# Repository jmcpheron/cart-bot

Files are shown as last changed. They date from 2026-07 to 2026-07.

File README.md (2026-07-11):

# cart-bot — Garage Kiva-Bot

Two small autonomous ground robots that work as a coordinated pair to move loaded
garage shelving units, inspired by Amazon's Kiva robots. Each robot slides under a
skid attached to a 2×4 ft metal shelf, lifts it 1–2 inches with a lead screw, and
repositions it on mecanum wheels. The pair synchronizes over ESP-NOW.

**Current phase: the kitchen tester** — a minimal mecanum platform that validates
drive geometry, ESP32 firmware, and the ESP-NOW control link before the production
build. See [docs/project-brief.md](docs/project-brief.md) for the full vision.

## Repo map

| Path | Contents |
|---|---|
| `docs/project-brief.md` | Full project brief (with hardware corrections applied) |
| `docs/kitchen-tester/` | Build guide, wiring/pin map, test plan for the tester |
| `docs/production/roadmap.md` | Next steps after the kitchen tests pass |
| `docs/devlog.md` | Development log — the story so far, wrong turns included |
| `docs/kitchen-tester/tracker-quickref.md` | Tracker cheat sheet: live view, aiming, command ladder |
| `docs/production/tracker-setup.md` | Overhead-camera tracking: mounting, markers, bring-up |
| `firmware/` | PlatformIO project: `robot` + `transmitter` + `camera` targets, host-run unit tests |
| `cad/` | STEP design revisions, OpenSCAD sources, generated STL/reports/previews |
| `tools/cadlab/` | CAD revision tracker (uv/Python): inspect, diff, build, render |
| `tools/tracker/` | Overhead-camera ArUco tracker + closed-loop waypoint control (uv/Python) |
| `hardware/bom.md` | Bill of materials — on-hand tester parts and production shopping list |

## Firmware quickstart

```sh
cd firmware
pio test -e native          # kinematics unit tests, runs on your Mac, no hardware
pio run -e robot            # build robot firmware
pio run -e robot -t upload  # flash the robot ESP32 over USB
pio device monitor          # serial console (115200) — type `help`
pio run -e transmitter -t upload   # flash the second ESP32 (Test 3)
pio run -e camera -t upload        # flash the overhead ESP32-CAM (GPIO0 jumper first)
```

WiFi credentials for the LAN (camera + tracker) come from `secrets.env` at
the repo root — see `secrets.env.example`. Closed-loop tracking lives in
`tools/tracker/`; setup guide: [docs/production/tracker-setup.md](docs/production/tracker-setup.md)

After wiring, `spin` on the serial console cycles each wheel in turn to verify
the harness. Full wiring diagram + point-to-point checklist:
[docs/kitchen-tester/wiring.md](docs/kitchen-tester/wiring.md)

## Driving

Everything is hosted on the robot itself: join Wi-Fi **`cartbot-robot`**
(password in `firmware/src/robot/config.h`) and open **http://192.168.4.1**

- `/` — drive page: dual thumb-pads (left = forward/strafe, right = rotate,
  true multi-touch), speed scale, invert toggles, STOP. Pair a Bluetooth
  gamepad (e.g. a Joy-Con) with your **phone** and the page reads it via the
  browser Gamepad API — no firmware Bluetooth.
- `/tune` — per-motor raw-duty tuning + the RL pin-role finder.

### Dances (turtle programming + record/replay)

The drive page's **dance** panel programs LOGO-style step sequences
(forward 1s, rotate ⟳ 0.5s, pause, …) or records your live driving and
compresses it into editable steps. Programs play **on the robot** (they
survive the phone sleeping; the failsafe watchdog stays armed; any manual
input or STOP aborts instantly) and can be saved to 4 flash slots that
survive reboots. Playback is open-loop, so dances drift with wheel slip —
closed-loop tracking is on the production roadmap.

The second ESP32 (`transmitter` env) is no longer needed for driving; it
remains in the repo as the ESP-NOW testbed seeding the production two-robot
coordination. If both are powered, an active drive/tune page takes priority
and ESP-NOW resumes ~1s after the page goes idle.

## Status

- [x] Repo scaffold, docs, firmware skeleton, printable part sources
- [x] `mecanum::mix()` implemented — normalize-on-overflow, 10/10 tests green
- [x] Failsafe policy implemented — limp/stop ladder on command silence + battery
- [ ] Test 1 — bench motor sanity (FL verified on bench; FR/RL/RR pending)
- [ ] Test 2 — full drive on kitchen floor (serial `demo` command)
- [ ] Test 3 — ESP-NOW remote control (link verified 0-drop on bench; driving pending)
- [ ] Test 4 — sustained run + battery baseline

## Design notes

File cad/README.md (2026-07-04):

# Printed Parts

OpenSCAD sources in `openscad/`, design revisions as STEP in `step/`,
generated STLs in `stl/`, metric reports in `reports/`, previews in `img/`.

## Tracking design revisions

Chassis revisions are exported from Onshape as numbered STEP files
(`step/tt-mount-chassis-<n>.step`) with an optional `<name>.meta.toml` sidecar
holding design notes. The `tools/cadlab` CLI (ported from
[jmcpheron/pycon2026](https://github.com/jmcpheron/pycon2026)) turns each into
a diffable snapshot; CI (`.github/workflows/cad.yml`) regenerates everything
on push and auto-commits, so **the git diff of `reports/*.txt` is the design
change record**.

```sh
# from the repo root
uv run --project tools/cadlab pytest tools/cadlab/tests   # self-test
uv run --project tools/cadlab cadlab all                  # regen reports/stl/png
uv run --project tools/cadlab cadlab diff \
    cad/step/tt-mount-chassis-1.step cad/step/tt-mount-chassis-2.step
```

`diff` prints a markdown delta table (bbox, volume, surface area, PLA mass,
solids, triangles) between any two revisions — STEP files or report TOMLs.

Explainer pages for notable revisions live in `docs/design/`:
[chassis rev 1 → rev 2](../docs/design/chassis-rev1-to-rev2.md).

## Parts

| Part | Qty | Material | Settings | Notes |
|---|---|---|---|---|
| Jason's chassis | 1 | — | — | **The chassis actually in use** (vertical motor mounts, wheels outboard). Onshape design, tracked as `step/tt-mount-chassis-<n>.step` revisions |
| `cable-clip` | 4–6 | PLA | 0.2mm, 100% | Prints on its side, no supports |
| `tt-motor-bracket` | 0–4 | PLA | 0.2mm, 3 walls, 25% | **Unused** — superseded by Jason's chassis. Kept for the alternative flat-plate build |
| `chassis-plate` | 0–1 | PETG | 0.28mm, 4 walls, 30% | **Unused** — alternative flat-plate chassis, needs ~200mm bed |

## Regenerating STLs

Shared dimensions live in `openscad/params.scad`. After editing:

```sh
cd cad
for p in tt-motor-bracket cable-clip chassis-plate; do
  openscad -o stl/$p.stl openscad/$p.scad
done
```

Commit both the `.scad` change and the regenerated `.stl`.

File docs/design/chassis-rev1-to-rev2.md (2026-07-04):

# Chassis: rev 1 → rev 2

*2026-07-03 · after the first four-wheel spin test on rev 1*

Two problems surfaced when the mecanum wheels went onto the printed rev 1
chassis: the wheel hubs didn't fit through the cradle wall openings, and the
deck was wider than it needed to be. Rev 2 fixes both — **hub bores enlarged
Ø6 → Ø10 mm** (with an entry slot so the hub drops in) and the **deck narrowed
by 20 mm**.

## Side by side

| rev 1 — printed & tested | rev 2 — printing |
|:---:|:---:|
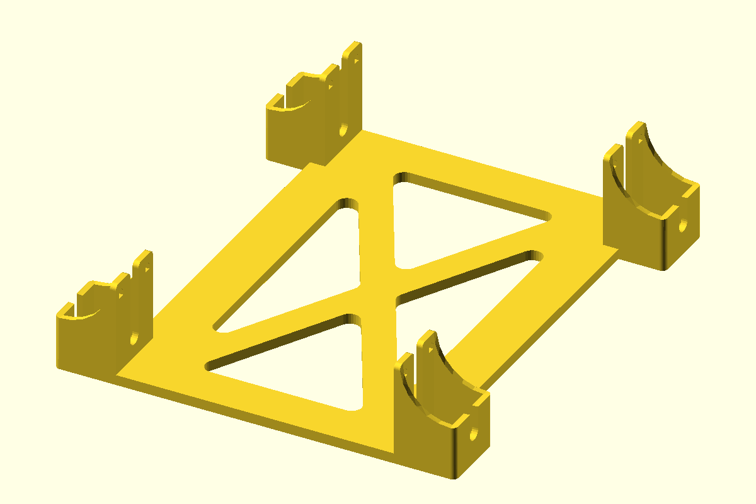
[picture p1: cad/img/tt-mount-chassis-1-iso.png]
rev 1 iso
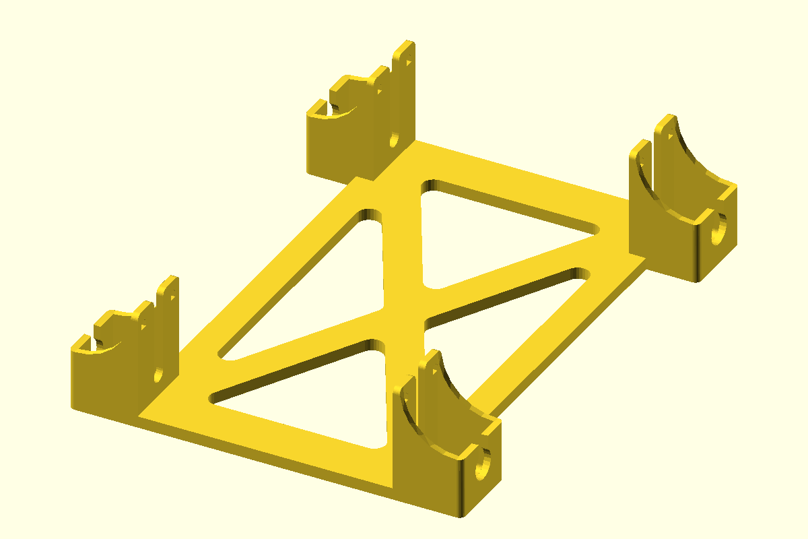
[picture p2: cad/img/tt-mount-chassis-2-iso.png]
rev 2 iso
|  |  |
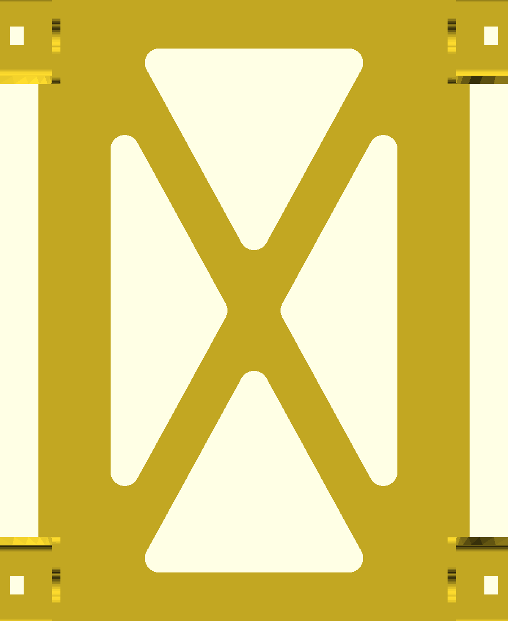
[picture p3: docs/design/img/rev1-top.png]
rev 1 top
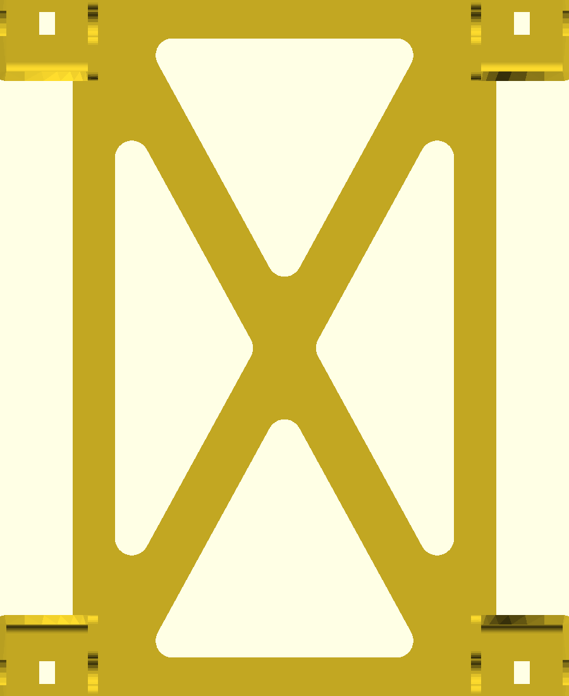
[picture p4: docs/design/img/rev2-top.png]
rev 2 top
|  |  |
| 156 × 180 × 40 mm | **136** × 180 × 40 mm |

## What changed, by the numbers

Generated with `cadlab diff` from the exact STEP geometry:

| Metric | rev 1 | rev 2 | Δ | Δ% |
|---|---|---|---|---|
| Bounding box X (mm) | 156.0 | 136.0 | −20.0 | **−12.8%** |
| Bounding box Y (mm) | 180.0 | 180.0 | 0 | — |
| Bounding box Z (mm) | 40.0 | 40.0 | 0 | — |
| Volume (mm³) | 77,289 | 62,548 | −14,741 | **−19.1%** |
| Surface area (mm²) | 56,000 | 48,421 | −7,580 | −13.5% |
| PLA @ 100% infill (g) | 95.8 | 77.6 | −18.2 | −19.0% |
| Solids | 5 | 5 | 0 | — |

Almost all of the removed volume is the deck narrowing; the bore enlargement
is geometrically small but is the change that makes the wheels mountable.

## The hub bore, in cross-section

Both revisions sliced by the **same plane** (x = −66 mm, through the
front-left motor cradle, perpendicular to the wheel axle). Gray fill is
rev 1; orange outline is rev 2:

cradle cross-section overlay

Rev 1's cradle wall had only a Ø6 shaft pass-through — the small gap visible
in the gray wall. Rev 2 opens it to a **Ø10 bore with a slot out to the motor
pocket**, so the wheel's hub collar passes through the wall instead of
colliding with it, and there's clearance around the hub while it spins.

Measured straight from the STEP's cylindrical faces (four bores each):

| | rev 1 | rev 2 |
|---|---|---|
| Hub bore radius | 3.0 mm | **5.0 mm** |
| Bore axis | along X (wheel axle), center 10.3 mm above the deck | unchanged |
| Cradle saddle (motor seat) | r 19.3 mm | unchanged |

The full-height slice (both left cradles, same plane) for context:

full cross-section overlay

## Reproducing this page's data

```sh
uv run --project tools/cadlab cadlab diff \
    cad/step/tt-mount-chassis-1.step cad/step/tt-mount-chassis-2.step
```

The cross-sections are exact BREP cuts (build123d slab-intersection at
x = −66, exported with `ExportSVG`), not mesh slices — the STL tessellation
isn't watertight enough for OpenSCAD's CGAL projection. Bore radii come from
enumerating the STEP's cylindrical faces (`GeomType.CYLINDER`).

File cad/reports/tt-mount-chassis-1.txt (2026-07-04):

File:           tt-mount-chassis-1.step
Schema:         AP242_MANAGED_MODEL_BASED_3D_ENGINEERING_MIM_LF { 1 0 10303 442 3 1 4 }
Originating:    ONSHAPE BY PTC INC, 1.217
Timestamp:      2026-07-04T05:18:35Z
Solids:         5   Top-level children: 5
Bounding box:   X[-78.257, 77.743]  Y[-89.952, 90.048]  Z[-1.705, 38.295]
Size:           156.0 × 180.0 × 40.0 mm
Volume:         77,289.1 mm³   (≈95.8 g PLA @ 100% infill)
Surface area:   56,000.0 mm²
Center of mass: (-0.257, 0.048, 3.658)
Tessellation:   2,588 triangles  (linear=0.1 mm  angular=0.5 rad)

Design metadata:
  design.revision: 1
  design.status: printed and tested
  design.date: 2026-07-03
  design.notes: Initial chassis: vertical TT motor mounts, wheels outboard on the D-shafts. Validated in the first four-wheel spin test.

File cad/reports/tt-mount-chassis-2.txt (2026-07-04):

File:           tt-mount-chassis-2.step
Schema:         AP242_MANAGED_MODEL_BASED_3D_ENGINEERING_MIM_LF { 1 0 10303 442 3 1 4 }
Originating:    ONSHAPE BY PTC INC, 1.217
Timestamp:      2026-07-04T05:22:29Z
Solids:         5   Top-level children: 5
Bounding box:   X[-68.257, 67.743]  Y[-89.952, 90.048]  Z[-1.705, 38.295]
Size:           136.0 × 180.0 × 40.0 mm
Volume:         62,547.7 mm³   (≈77.6 g PLA @ 100% infill)
Surface area:   48,420.5 mm²
Center of mass: (-0.257, 0.048, 4.403)
Tessellation:   2,700 triangles  (linear=0.1 mm  angular=0.5 rad)

Design metadata:
  design.revision: 2
  design.status: printing
  design.date: 2026-07-03
  design.changes_from: tt-mount-chassis-1
  design.notes: Bigger hub bore so the mecanum wheel hub fits through with clearance; deck narrowed.

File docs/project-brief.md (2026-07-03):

# Garage Kiva-Bot — Project Brief

## Project Summary

The goal is to build two small autonomous ground robots that work as a coordinated
pair to move loaded garage shelving units around the garage floor — inspired by the
Amazon Kiva/Robotics system. Each robot slides under a custom bottom skid attached
to a standard 2×4 ft metal garage shelf, lifts it 1–2 inches off the ground using a
lead screw mechanism, then repositions it using mecanum wheel drive. The two robots
communicate wirelessly (ESP-NOW) to synchronize their lift so the shelf stays level
during movement. When not in use, the robots return to an autonomous charging dock.

The full production system uses 12V geared motors with Hall encoders (JGB37-520),
BTS7960 high-current motor drivers, 4S 18650 battery packs, NEMA 17 steppers for
the lift, and MPU-6050 tilt sensing for safety. But before any of that gets built,
we validate the core ideas on a cheap kitchen-floor test platform first.

---

## Kitchen Tester — What It Is

The kitchen tester is a minimal, low-cost prototype that proves out the mecanum
drive geometry and ESP32 control code before committing to the full build. It is
not expected to lift anything. It is not expected to run for hours. It just needs
to drive in all eight directions, strafe cleanly, rotate in place, and respond to
commands from a second ESP32 over ESP-NOW.

### Hardware on Hand

| Item | Qty | Notes |
|---|---|---|
| DORHEA TT Motor + 69mm Wheel Kit | 4 sets | 3–6V, 1:48, ~200 RPM at 6V (kit wheels unused — mecanums replace them) |
| Eujgoov 48mm Mecanum Wheels | 2 pairs (4 wheels) | TT-shaft compatible, rubber rollers |
| BOJACK L298N Dual H-Bridge Driver | 4× (use 2) | Controls 2 motors each, 3.3V logic OK |
| URGENEX 7.4V 2S LiPo, 1000mAh, 35C | 2× (use 1) | JST connector, ~51g |
| ESP32 WROOM-32 (38-pin) | 2× from stash | Robot + transmitter; dual-core, ESP-NOW, PWM |

Two L298N boards cover all four motors (two motors per board). The LiPo feeds the
L298N motor supply directly at 7.4V; the L298N's onboard 5V regulator feeds the
ESP32's VIN pin. No separate power converter needed.

> **Power notes (corrections to the original draft):**
> - The L298N drops ~1.4–2.5V through its output transistors, so the 3–6V TT
>   motors see roughly 5–6V from the 7.4V pack. **This is a feature** — don't
>   "fix" it with a buck converter or the motors will be overdriven.
> - Keep the L298N's onboard 5V-regulator jumper **ON** (7.4V input gives the
>   78M05 enough headroom). Add a 470–1000µF electrolytic across the motor
>   supply near the drivers; motor stall transients otherwise cause ESP32
>   brownout resets. All grounds must be common.
> - A 100k/33k divider from pack + to GPIO 34 lets firmware watch pack voltage
>   and enforce the 6.8V (3.4V/cell) cutoff automatically.

### Chassis

A piece of 1/4-inch plywood or a printed plate, roughly 180–200mm square, with the
four TT motors mounted at the corners. Wheels must form the standard mecanum
X-pattern — viewed **from above**, the roller axes form an X:

```
FL ⟍   ⟋ FR
RL ⟋   ⟍ RR
```

Rollers on FL and RR lean one direction; FR and RL lean the other. This is what
enables sideways movement. **Getting this orientation wrong is the most common
first mistake — check it against `docs/kitchen-tester/build-guide.md` before
wiring anything.**

TT motors screw into printed brackets (`cad/`). The 48mm mecanum wheels press
directly onto the TT motor's D-shaft. No axle hardware needed for the tester.

---

## Wiring

See [`docs/kitchen-tester/wiring.md`](kitchen-tester/wiring.md) for the full pin
map and power tree. Key change from the original draft: the pin map avoids **all**
ESP32 strap pins (0, 2, 5, 12, 15) — the draft assigned GPIO 12, which selects
1.8V flash voltage if it reads high at boot and can prevent the board from booting.

---

## Firmware Structure

### Mecanum Kinematics

The core math takes three velocity inputs — forward (vx), strafe (vy), and turn
rate (ω) — and mixes them into four wheel speeds:

```
FL = vx + vy + ω
FR = vx − vy − ω
RL = vx − vy + ω
RR = vx + vy − ω
```

Sign convention: **vx+ = forward, vy+ = strafe right, ω+ = clockwise** (from
above). Each result is scaled and clamped to [−255, 255] and mapped to PWM duty +
direction pins. Open-loop at this stage — no encoders — the goal is validating
that the geometry produces the right movement. The math lives in
`firmware/lib/kinematics/` as a dependency-free library with host-run unit tests,
and is reused unchanged by the production robots.

### ESP32 Task Layout

Two FreeRTOS tasks on the dual-core ESP32:

- **Core 0 — Motor task:** reads the current velocity setpoint from a shared
  store, evaluates the failsafe policy, computes wheel speeds, updates PWM
  outputs every 20ms.
- **Core 1 — Comms task:** serial console + ESP-NOW receive. Updates the shared
  setpoint when a command arrives. Watchdog: no command for 500ms → failsafe.

### Command Protocol (ESP-NOW)

Packed struct, exactly 6 bytes (`firmware/lib/protocol/`):

```c
typedef struct __attribute__((packed)) {
    int8_t   vx;     // forward/back, -100..100
    int8_t   vy;     // strafe right/left, -100..100
    int8_t   omega;  // rotation CW/CCW, -100..100
    uint8_t  cmd;    // 0=drive, 1=stop, 2=ping
    uint16_t seq;    // sequence number for drop detection
} robot_cmd_t;
```

The transmitter sends this at ~10Hz; ESP-NOW frames carry their own CRC, so the
sequence number is only for measuring drops. The transmitter ESP32 hosts a Wi-Fi
AP with a phone-browser joystick page.

---

## Test Sequence

Full checklists with results logs: [`docs/kitchen-tester/test-plan.md`](kitchen-tester/test-plan.md).

1. **Power-up and motor sanity** — bench-test each motor/driver channel from the
   serial console before assembly.
2. **Full drive on kitchen floor** — forward/back, strafe, rotate, diagonal via
   the scripted `demo` sequence over USB serial.
3. **ESP-NOW control from second ESP32** — phone joystick → transmitter →
   robot; validate latency, watchdog, packet loss.
4. **Sustained run and battery life** — 15 min continuous, temperature and
   voltage logging; sets expectations for production 4S pack sizing.

---

## What This Proves (and What It Doesn't)

| Validated by kitchen tester | Deferred to production build |
|---|---|
| Mecanum drive geometry works | Torque under load (500+ lb shelf) |
| ESP32 mecanum firmware | Encoder closed-loop velocity control |
| ESP-NOW latency and reliability | Two-robot lift synchronization |
| Battery voltage/run-time baseline | Lead screw lift mechanism |
| L298N + ESP32 3.3V logic compatibility | BTS7960 high-current driver behavior |
| Basic obstacle response (manual) | Automated docking and charging |

---

## Printed Parts

Sources and print settings in [`cad/`](../cad/README.md):

- **TT motor brackets** — 4× corner cradles, PLA, non-structural.
- **Chassis plate** — optional printed alternative to plywood, PETG, 4mm.
- **Cable clips** — keep the LiPo lead and L298N jumpers out of the rollers.

---

## Next Steps After Kitchen Tests Pass

See [`docs/production/roadmap.md`](production/roadmap.md).

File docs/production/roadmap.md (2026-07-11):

# Production Roadmap — after the kitchen tests pass

## Next milestone: closed-loop tracking (kitchen scale)

Open-loop dances drift because the TT motors are inconsistent and the
mecanums skid — by design, position feedback is the fix, not better motors.
Plan, in increasing order of capability:

1. **Gyro heading-hold (cheap interim): BUILT — awaiting hardware bring-up.**
   MPU-6050 (GY-521) on I²C, SDA=GPIO13 SCL=GPIO33 (`src/robot/imu.{h,cpp}`,
   raw registers, no library). Yaw-hold PI (`lib/heading`) trims ω whenever
   the robot translates with w=0 — kills rotational drift, does nothing for
   position. Dances also gained gyro-terminated turns: `t,<deg>,<w>` steps
   (`lib/dancescript`) end at the measured angle, not a timer. Debug:
   `/imu` endpoint, serial `imu` command, "gyro square" preset on the drive
   page. NOTE before wiring: GPIO 33 was the ORIGINAL RL_IN1 — confirm no
   stray harness wire is still on it (same caveat as 32).
2. **Overhead camera + ArUco (the real thing): BUILT — see
   [tracker-setup.md](tracker-setup.md).** One downward-looking AI-Thinker
   ESP32-CAM (`pio run -e camera`) streams frames; `tools/tracker/` (uv
   project like cadlab) detects a printed ArUco marker on the robot's roof,
   maps it through a floor-marker homography, and sends `/cmd` corrections
   at 10 Hz. Waypoint following = `tracker goto` / `tracker route`.
   ESP32-CAMs never do vision themselves — they're too weak; they only
   stream.
3. **Multi-camera coverage:** only when one camera's view isn't enough
   (garage scale). Homographies + hand-off; genuinely advanced, defer.

1. **Order drivetrain hardware** — JGB37-520 12V gearmotors with Hall encoders,
   BTS7960 drivers, 4S 18650 pack + BMS.
2. **Design production chassis** in Onshape — 2020 aluminum extrusion or bent
   sheet metal; link the Onshape doc here and commit exported STEP/STL to `cad/`.
3. **Closed-loop velocity control** — encoder ISRs + PID per wheel; reuse
   `lib/kinematics` unchanged, the mix output becomes a velocity setpoint instead
   of a PWM duty.
4. **Safety** — MPU-6050 tilt sensing, tilt-abort on lift; extend the failsafe
   policy from the tester (`src/robot/failsafe.cpp` is the seed).
5. **Lift sub-assembly** — NEMA 17 + lead screw; 1,000-cycle stress test rig.
6. **Shelf skid frame** — square steel tube, H-shape, for the 2×4 ft shelves.
7. **Two-robot coordination** — extend `lib/protocol` from one-way drive
   commands to a leader/follower lift-sync handshake (the seq/ack groundwork is
   validated by kitchen Test 3).
8. **Docking + charging** — autonomous return to dock; contact pads.

## Open questions to resolve before ordering

- Shelf + contents worst-case weight → wheel count/size and motor torque margin.
- Garage floor surface (sealed concrete?) → mecanum roller compound choice.
- Lift point geometry on the 2×4 shelves → skid design drives robot footprint.

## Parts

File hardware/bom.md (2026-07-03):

# Bill of Materials

## Kitchen tester (on hand)

| Item | Qty used / on hand | Notes |
|---|---|---|
| DORHEA TT motor, 1:48, 3–6V | 4 / 4 | Kit's 69mm plastic wheels unused |
| Eujgoov 48mm mecanum wheels | 4 / 4 | 2 left + 2 right; split pairs across diagonals |
| BOJACK L298N dual H-bridge | 2 / 4 | Spares cover a blown board |
| URGENEX 2S LiPo 7.4V 1000mAh 35C | 1 / 2 | JST; second pack for swap during long tests |
| ESP32 WROOM-32 38-pin dev board | 2 / stash | Robot + transmitter |

## Kitchen tester (to buy / find in stash)

| Item | Qty | Notes |
|---|---|---|
| 470–1000µF ≥16V electrolytic cap | 1–2 | Bulk cap across motor rail (brownout fix) |
| 100kΩ + 33kΩ resistors, 1% | 1 ea | Battery sense divider → GPIO 34 |
| M3 screws (×30 for motors, ×8 for brackets) + nuts | ~20 | TT motor mounts |
| Dupont jumpers, 20cm | ~20 | Logic wiring |
| 18–20 AWG silicone wire | 1m | Battery → drivers |
| JST connector pigtail | 1 | Match the URGENEX pack |
| Velcro strap | 1 | Battery retention |
| Chassis: 1/4" plywood offcut ~200mm sq | 1 | Or print `chassis-plate` in PETG |

## Production build (deferred — do not order until kitchen tests pass)

| Item | Qty (per robot × 2) | Notes |
|---|---|---|
| JGB37-520 12V gearmotor w/ Hall encoder | 4 | Torque spec TBD by shelf weight measurement |
| BTS7960 43A driver | 4 | One per motor for closed-loop |
| Mecanum wheels, 97mm+ steel hub | 4 | Roller compound TBD by floor surface |
| NEMA 17 stepper + lead screw (Tr8x8) | 1 | Lift mechanism |
| Stepper driver (TMC2209 or DM542) | 1 | |
| MPU-6050 IMU | 1 | Tilt-abort |
| 4S 18650 pack + BMS | 1 | Capacity TBD from Test 4 baseline |
| ESP32 WROOM-32 | 1 | Same firmware family as tester |
| Steel square tube for shelf skid | — | H-frame per shelf |

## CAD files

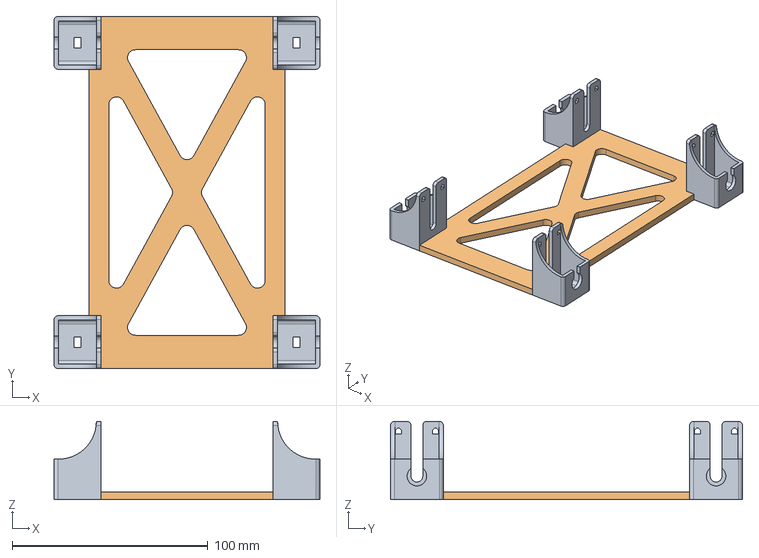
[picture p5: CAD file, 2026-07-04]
cad/step/tt-mount-chassis-2.step
136.0 x 180.0 x 40.0 mm
tt-mount x 4

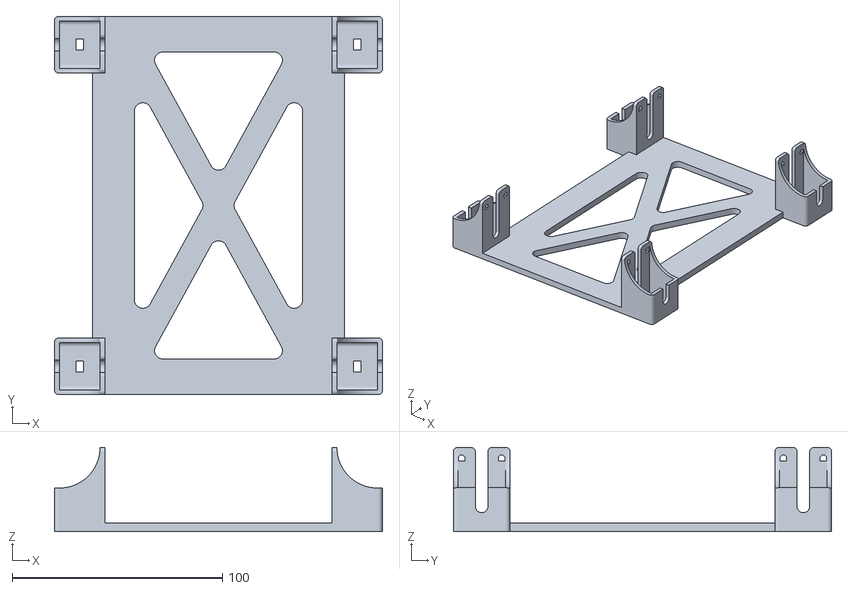
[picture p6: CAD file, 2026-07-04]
cad/stl/onshape-chassis-and-tt-mounts.stl
156.0 x 180.0 x 40.0

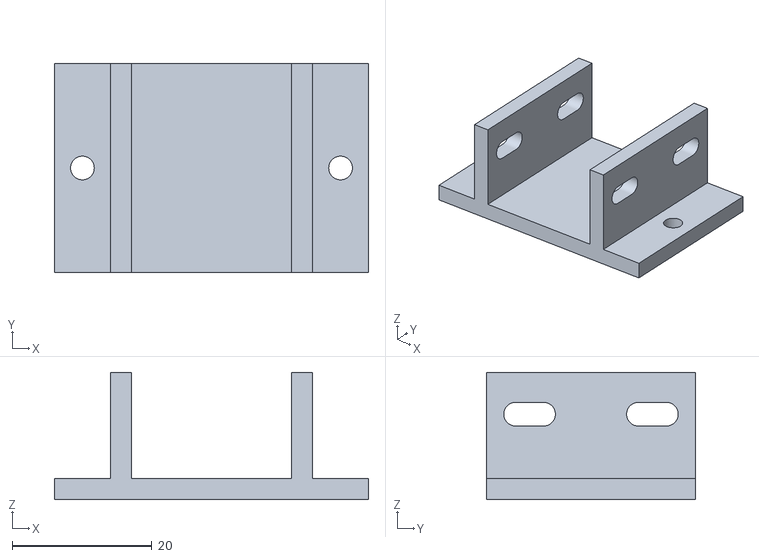
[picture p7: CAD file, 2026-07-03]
cad/stl/tt-motor-bracket.stl
45.0 x 30.0 x 18.2

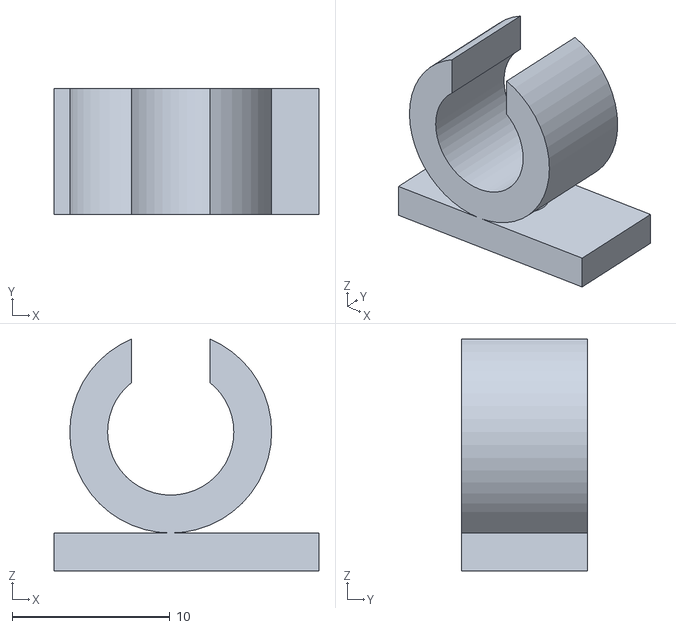
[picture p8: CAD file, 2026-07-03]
cad/stl/cable-clip.stl
16.8 x 8.00 x 14.7

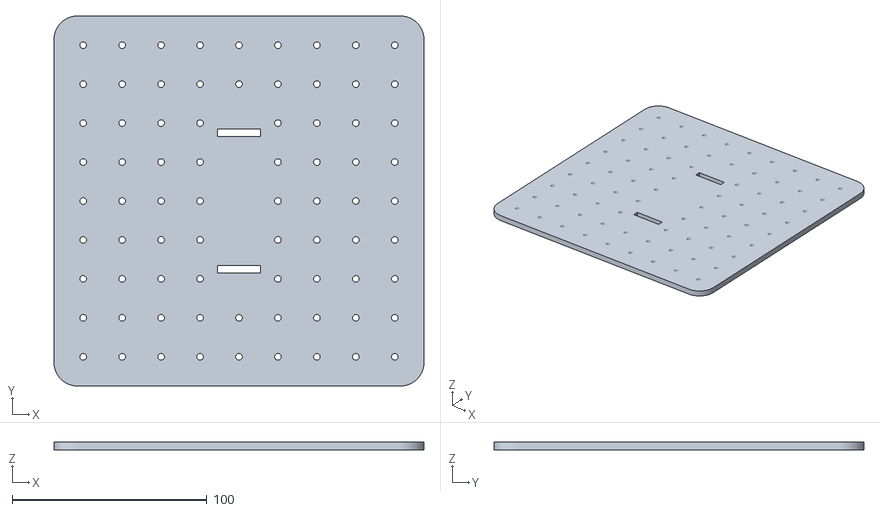
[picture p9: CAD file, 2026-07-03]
cad/stl/chassis-plate.stl
190.0 x 190.0 x 4.00

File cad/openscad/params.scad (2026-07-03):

// Shared dimensions for the kitchen tester printed parts.
// ⚠ TT motor clones vary by ±0.5mm — measure YOUR DORHEA motors and print ONE
// bracket to check fit before running off all four.

// ---- TT motor (yellow gearbox type) ----
tt_body_len    = 65.0;   // gearbox + can, excluding shaft
tt_body_w      = 22.5;   // across the flats
tt_body_h      = 18.5;
tt_hole_d      = 3.2;    // M3 clearance
tt_hole_space  = 17.6;   // between the two gearbox through-holes — MEASURE THIS
tt_hole_z      = tt_body_h / 2;  // holes run through mid-height of the box

// ---- printing ----
fit_clr   = 0.25;  // per-side clearance for press/slide fits
wall      = 3.0;
m3_clr    = 3.4;   // M3 clearance hole
$fn       = 48;

// ---- chassis ----
plate_size  = 190;   // square, mm
plate_thick = 4;
grid_pitch  = 20;    // M3 mounting-hole grid

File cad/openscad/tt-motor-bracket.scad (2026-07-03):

// TT motor bracket — U-channel cradle, 4 needed (all identical).
//
// The motor drops into the channel; two M3×30 screws pass through both walls
// and the motor's gearbox through-holes. Wall holes are SLOTS (±2mm along the
// motor axis) to absorb clone-to-clone hole-position variance. The base bolts
// to the chassis plate with two M3 screws on the 20mm grid.
//
// Print: PLA, 0.2mm layers, 3 perimeters, 25% infill, no supports
// (slots print as bridges — they're short, any printer handles it).

include <params.scad>

channel_w  = tt_body_w + 2 * fit_clr;       // motor slides in
bracket_len = 30;                            // along the motor axis
wall_h     = tt_hole_z + 6;                  // wall covers holes + margin
base_thick = 3;
base_ear   = 8;                              // ear width outside each wall
slot_len   = 4;                              // hole slop along motor axis

module wall_slot() {
    // M3 through-slot at motor-hole height, elongated along motor axis (Y)
    hull()
        for (y = [-slot_len/2, slot_len/2])
            translate([0, y, base_thick + tt_hole_z])
                rotate([0, 90, 0])
                    cylinder(d = m3_clr, h = 100, center = true);
}

module tt_motor_bracket() {
    difference() {
        union() {
            // base with mounting ears
            translate([-(channel_w/2 + wall + base_ear), -bracket_len/2, 0])
                cube([channel_w + 2*(wall + base_ear), bracket_len, base_thick]);
            // two walls
            for (s = [-1, 1])
                translate([s*(channel_w/2 + wall/2) - wall/2, -bracket_len/2, 0])
                    cube([wall, bracket_len, base_thick + wall_h]);
        }
        // motor through-screw slots (both walls at once)
        for (y = [-tt_hole_space/2, tt_hole_space/2])
            translate([0, y, 0]) wall_slot();
        // chassis mounting holes, one per ear, on-axis
        for (s = [-1, 1])
            translate([s*(channel_w/2 + wall + base_ear/2), 0, -1])
                cylinder(d = m3_clr, h = base_thick + 2);
    }
}

tt_motor_bracket();

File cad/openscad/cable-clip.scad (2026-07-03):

// Cable clip — open C-clip with an M3 base hole. Print a handful; mecanum
// rollers eat any wire loose enough to droop.
// Print: PLA, 0.2mm, 100% infill (tiny part), no supports (prints on its side).

include <params.scad>

bundle_d  = 8;     // wire bundle diameter
clip_wall = 2.4;
clip_w    = 8;     // width along the wire
mouth     = 5;     // opening gap — wires push through, then it holds

module cable_clip() {
    rotate([90, 0, 0])  // lay on its side for printing
    union() {
        difference() {
            cylinder(d = bundle_d + 2*clip_wall, h = clip_w);
            translate([0, 0, -1]) cylinder(d = bundle_d, h = clip_w + 2);
            // mouth opening, facing up
            translate([-mouth/2, 0, -1])
                cube([mouth, bundle_d, clip_w + 2]);
        }
        // foot with M3 hole
        translate([-clip_wall - 5, -(bundle_d/2 + clip_wall) - 2.4, 0])
        difference() {
            cube([bundle_d + 2*clip_wall + 4, 2.4, clip_w]);
            translate([(bundle_d + 2*clip_wall + 4)/2, -1, clip_w/2])
                rotate([-90, 0, 0]) cylinder(d = m3_clr, h = 5);
        }
    }
}

cable_clip();

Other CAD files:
cad/step/tt-mount-chassis-1.step
cad/openscad/chassis-plate.scad
cad/stl/tt-mount-chassis-1.stl
cad/stl/tt-mount-chassis-2.stl

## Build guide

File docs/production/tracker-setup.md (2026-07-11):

# Overhead camera tracking — setup & bring-up

Roadmap Milestone 2, first working version: one AI-Thinker ESP32-CAM on the
kitchen ceiling, ArUco markers on the robot and floor, `tools/tracker/` on
the Mac closing the loop through the robot's existing `/cmd` endpoint.

Division of labor (unchanged from the roadmap): the ESP32-CAM **only
streams**; the robot ESP32 stays a **dumb motor controller** behind its
existing failsafe; all vision and control run on the host.

## 1. One-time setup

### Secrets
```
cp secrets.env.example secrets.env     # repo root, gitignored
# edit: HOME_WIFI_SSID / HOME_WIFI_PASS
```
Both firmware builds pick the credentials up automatically
(`firmware/load_secrets.py`). No file → AP-only firmware, as before.

### Flash the robot
```
cd firmware && pio run -e robot -t upload && pio device monitor
```
Serial prints the LAN IP (`[comms] LAN http://…`) and warns if the router's
channel breaks the legacy transmitter link (remedy: pin the router's 2.4 GHz
band to channel 1, or ignore — the tracker replaces the transmitter).
Check from the Mac: `curl 'http://cartbot.local/cmd?vx=0&vy=0&w=0'`

### Flash the camera (bare board — no auto-reset)
1. FTDI on **5V**, wired to the ESP32-CAM (TX↔U0R, RX↔U0T, GND, 5V).
2. Jumper **GPIO0 → GND**, press RESET (enters bootloader).
3. `cd firmware && pio run -e camera -t upload`
4. Remove the jumper, press RESET again.
5. `pio device monitor -e camera` → prints `[cam] ready — …/jpg`.

Browser check: `http://cartbot-cam.local:81/stream` (aiming view),
`http://cartbot-cam.local/jpg` (what the tracker polls),
`/status`, and `/set?framesize=uxga` for runtime tuning.

### Print the markers
```
cd tools/tracker && uv run tracker markers
```
Five US-Letter pages in `out/markers/`: robot marker (id 0) + floor markers
(ids 10–13), all 15 cm. **Print at 100% scale** and tape-measure the ruler
bar on each sheet — it must read exactly 10 cm. Mount on cardboard/foamboard
so they lie dead flat; curl ruins corner accuracy.

## 2. Physical layout

- **Camera**: kitchen ceiling (~2.4 m), lens pointed straight down over the
  test area (within ~10° of vertical is fine — the homography absorbs it).
  At 2.2 m above the floor the OV2640's ~66°×49° FOV covers about
  **2.9 × 2.0 m**. Power from a **solid 5 V / 2 A** wall adapter with a short,
  thick USB cable — long thin cables brown out the ESP32-CAM the moment WiFi
  transmits (this is the #1 bring-up killer).
- **Floor markers 10–13**: tape one near each corner of the camera's view,
  **axis-aligned**, printed arrow ("TOP EDGE") pointing the same way on all
  four — that direction becomes **+y**. Marker 10 is the room origin; +x runs
  toward marker 11. Tape-measure each marker's **center** from marker 10's
  center and write the numbers into `tools/tracker/config/room.yaml`.
- **Robot marker 0**: flat on the top plate, arrow pointing forward (any
  error gets measured by `tracker jog` into `yaw_offset_deg`).

Detection target: the 15 cm markers are ~42 px across at SVGA from that
height — comfortably above the ~40 px reliability floor. If detection is
flaky: lock exposure (`/set?aec=0&aec_value=300`), then raise resolution
(`/set?framesize=uxga`, ~5 fps is fine — the robot is slow), and only then
consider AprilTag (isolated inside `src/tracker/detect.py`).

## 3. Bring-up (each step gates the next)

```
cd tools/tracker
uv run tracker view        # all 5 markers detected in >90% of frames
uv run tracker calibrate   # homography, must report RMS < 3 px
uv run tracker pose        # push the robot by hand; coords track the tape measure
uv run tracker jog         # pulses each axis; paste the printed signs/yaw block into room.yaml
uv run tracker hold        # robot fights back when pushed; tune kp gains here
uv run tracker goto 100 75 # drive to a point; click the window to retarget
uv run tracker route demo.yaml   # waypoint list — "drive the square FOR REAL"
```

Gain tuning in `hold`: raise `control.kp_lin` (room.yaml) until the robot
faintly oscillates around the target, then back off ~30%. Same for `kp_ang`.

## 4. Safety model

- The tracker sends `/cmd` at 10 Hz. The robot's own failsafe
  (`firmware/src/robot/failsafe.cpp`) limps at 500 ms of silence and stops at
  1500 ms — killing the tracker process (or the WiFi) stops the robot.
- Marker lost > 0.5 s → tracker sends one explicit `0,0,0` then goes silent.
- `q` quits any window, space bar clears the target and stops, Ctrl-C stops.
- The tracker continuously reprojects the floor markers; a "CAMERA MOVED?"
  HUD warning means recalibrate before trusting coordinates.

## 5. Latency & where this goes next

`/jpg` polling + `CAMERA_GRAB_LATEST` on the camera bounds frame staleness to
roughly one frame + network time; the HUD shows frame age live. If p95 age
exceeds ~300 ms, move the tracker onto lovelace (Ethernet, always on) — it's
plain Python + OpenCV, nothing Mac-specific.

Multi-camera tiling later: every camera gets its own homography into the
same floor-marker room frame, so fusion is "prefer the camera that sees the
robot" — the coordinate system already agrees. That work lives entirely in
`src/tracker/homography.py` + a camera list in room.yaml.

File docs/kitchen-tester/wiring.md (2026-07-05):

# Kitchen Tester — Wiring (as built)

Wiring diagram

Boards are named by their **physical position on the chassis**: the FRONT
board drives FL + FR, the REAR board drives RR + RL. (History: the harness
was originally documented with the power board at the front; the build ended
up 180° rotated. These tables describe the machine as it exists — verified
corner-by-corner with the `spin` test and a floor drive on 2026-07-04.)

The pin map's source of truth is `firmware/src/robot/pins.h` — if this doc
and the code disagree, the code wins and this doc has a bug.

## Harness checklist (point-to-point)

### Power

| ✓ | From | To | Wire |
|---|---|---|---|
| ☑ | LiPo + (JST red) | REAR board `12V` terminal | 18–20 AWG red |
| ☑ | Rear board `12V` | Front board `12V` (daisy-chain) | 18–20 AWG red |
| ☑ | LiPo − (JST black) | REAR board `GND` terminal | 18–20 AWG black |
| ☑ | Rear board `GND` | Front board `GND` | 18–20 AWG black |
| ☑ | Bulk cap 470–1000µF | across rear board `12V` ↔ `GND` — **stripe (−) to GND** | leads |
| ☑ | Rear board `GND` | ESP32 `GND` pin | black Dupont |
| ☑ | Rear board `5V` | ESP32 `VIN` — **untethered driving only, never with USB** | red Dupont |

### Front board signals (drives FL + FR)

| ✓ | ESP32 GPIO | Board pin | Function |
|---|---|---|---|
| ☑ | 14 | ENA | FL speed (PWM) — note: this channel's wires sit one position shifted (ENA-first header); roles verified with the pin-role finder |
| ☑ | 23 | IN1 | FL direction |
| ☑ | 22 | IN2 | FL direction |
| ☑ | 19 | IN3 | FR direction |
| ☑ | 18 | IN4 | FR direction |
| ☑ | 21 | ENB | FR speed (PWM) |

### Rear board signals (drives RR + RL)

| ✓ | ESP32 GPIO | Board pin | Function |
|---|---|---|---|
| ☑ | 25 | IN1 | RR direction |
| ☑ | 26 | IN2 | RR direction |
| ☑ | 27 | ENA | RR speed (PWM) |
| ☑ | 16 | IN3 | RL direction |
| ☑ | 17 | IN4 | RL direction |
| ☑ | 4  | ENB | RL speed (PWM) |

### Motors

| ✓ | Motor | Terminals |
|---|---|---|
| ☑ | FL | Front board OUT1 / OUT2 |
| ☑ | FR | Front board OUT3 / OUT4 |
| ☑ | RR | Rear board OUT1 / OUT2 |
| ☑ | RL | Rear board OUT3 / OUT4 |

### Board jumper states (both boards)

- ENA / ENB plastic jumpers: **removed** (we PWM those pins)
- 5V-EN regulator jumper: **installed** (board logic runs from the LiPo)

## Pin map summary (matches pins.h)

| Corner | Board / channel | in1 | in2 | en |
|---|---|---|---|---|
| FL | front / OUT1-2 | 23 | 22 | 14 |
| FR | front / OUT3-4 | 19 | 18 | 21 |
| RL | rear / OUT3-4 | 17 | 16 | 4 |
| RR | rear / OUT1-2 | 25 | 26 | 27 |

`in1`/`in2` order in pins.h encodes each motor's *polarity* (calibrated by
floor test) and may be swapped relative to the physical IN numbering — that's
normal and intended.

Strap pins 0, 2, 5, 12, 15 unused. Free for future: 13, 32, 33,
34 (reserved: battery sense). Never use 35/36/39 (input-only).

## Power-up sequence (assembled robot)

1. **USB session (bench / flashing):** 5V → VIN wire **disconnected**.
   USB first, then LiPo.
2. **Untethered session (floor):** USB unplugged. Connect 5V → VIN, then
   the LiPo.
3. **Never both.** USB + the 5V link back-feed each other.
4. Power-down in reverse: LiPo off first, always.

## Bring-up after any rewiring

1. `spin` (serial or ask Claude) — confirm **which physical corner** each
   labeled slot moves. Labels ≠ corners is the most common rebuild bug: the
   wiring can be perfectly healthy and still rotated 180°.
2. Floor test from the drive page: forward-only at low speed. The robot's
   motion decodes polarity errors (backward = all flipped; spin = one side;
   sideways = one diagonal; veer = one wheel).
3. Fix everything in `pins.h` (corner ↔ pin-set assignment + in1/in2
   polarity). Wires only move if you want them to.

## Battery sense divider (future add)

```
LiPo (+) ──[100kΩ]──┬──[33kΩ]── GND
                    └────────── ESP32 GPIO 34
```

When wired: set `kBatterySenseWired = true` in `firmware/src/robot/battery.h`,
reflash, calibrate `kDividerRatio` against a multimeter via `batt`.

## Troubleshooting (lessons collected on this build)

- **One direction dead, other fine** → either a broken IN wire, or **the
  roles are shifted**: L298N headers read **ENA, IN1, IN2** (enable FIRST)
  per channel. Wire positionally as "IN1, IN2, EN" and one "direction"
  simply disables the bridge. Channel B (IN3, IN4, ENB) is immune, which is
  why only one channel misbehaves. Diagnose with the tuning page's
  **pin-role finder** (`/tune`) — the config that moves the wheel BOTH ways
  reveals where each wire landed. Fix in `pins.h`, no rewiring.
- **Controls scrambled after a rebuild (forward strafes, strafe rotates)** →
  labels don't match corners and/or polarities flipped. Run the bring-up
  sequence above; it's always a `pins.h` fix.
- **A wire dead through part swaps** → check it isn't on an input-only pin
  (34/35/36/39). And when a fault survives every part swap, suspect the
  *convention* being faithfully reproduced, not the parts.
- **Motors stutter only while a web page is driving** → two command streams
  racing (e.g. transmitter keep-alives vs page). Web sessions preempt
  ESP-NOW for 1s windows by design; if it recurs, check `stats`.

## Power notes

- The L298N drops ~1.4–2.5V: 3–6V TT motors on a 7.4V pack is intentional.
- The bulk capacitor prevents ESP32 brownouts when motors stall.
- PWM is 1kHz (`motors.cpp`) — the L298N's slow bridge loses short pulses
  at higher frequencies; whine under partial throttle is normal.

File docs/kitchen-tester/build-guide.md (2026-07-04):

# Kitchen Tester — Build Guide

## 1. Chassis

The chassis is Jason's own 3D-printed design: motors mounted vertically at the
four corners, wheels outboard on the TT D-shafts. (An unused alternative — a
flat printed plate with a hole grid — lives in `cad/openscad/chassis-plate.scad`
if a rebuild is ever needed. Drop the actual chassis STL/source into `cad/stl/`
to version it with the project.)

Whatever the mount style, two geometric requirements matter to the software:

1. **All four wheel axles parallel**, pointing left-right, wheels at the
   corners of a rectangle. The mixing math assumes this.
2. **The mecanum X-pattern** — see the next section, and check it *after*
   every wheel-swap or rebuild.

## 2. Mecanum X-pattern — check this three times

This is the highest-risk assembly step, doubly so with a custom mount
orientation. Viewed **from above**, the roller axes must form an **X**
(also drawn in the [wiring diagram](img/wiring.svg)):

```
        FRONT
   FL \     / FR
   RL /     \ RR
        REAR
```

Practical check per wheel: look at the roller **touching the ground** — its
axis must point at the **center of the robot**. Mecanum wheels come in left-
and right-handed pairs; each pair splits across a *diagonal* (FL+RR one
handedness, FR+RL the other).

Symptoms of getting it wrong:
- Strafe command → robot **rotates or crabs** instead of moving sideways:
  two wheels are swapped.
- Strafe command → wheels spin, robot **vibrates in place**: the pattern is
  an O instead of an X — swap left and right wheels on both axles.

## 3. Motor mounting

- Motors bolt through their gearbox holes with M3×30 screws. With vertical
  mounts, double-check the output shafts all sit on the same axle line
  front-to-back and the same height left-to-right — a tilted wheel loads one
  roller edge and ruins strafing.
- Press mecanum wheels onto the D-shafts; seat the hub grub screw (if present)
  on the flat of the D.

## 4. Electronics placement

- **Board A (front)** between the front motors, **Board B (rear)** between the
  rear motors — keeps motor leads short; heatsinks up.
- ESP32 mid-deck, USB port reachable (you'll flash and bench-drive a lot).
- LiPo velcro-strapped at the center of mass — centered mass makes rotation
  predictable.
- Bulk capacitor across Board A's supply terminals.
- Clip or zip-tie every wire away from the wheels (`cad/openscad/cable-clip.scad`
  prints in minutes) — mecanum rollers eat loose Dupont leads.

## 5. Wiring

Follow the harness checklist in [`wiring.md`](wiring.md) — every wire is a
row you can tick off, and the diagram shows the full layout. Sequence: motor
leads first, then logic, battery last. Meter-check LiPo polarity at the screw
terminals before first connect; reverse polarity kills an L298N instantly.

## 6. Four-wheel bring-up

1. Flash (`pio run -e robot -t upload`), open the console
   (`pio device monitor`).
2. Run `spin` — each wheel spins in turn (FL → FR → RL → RR, 2s each, labeled).
   Wrong wheel moves = crossed board/channel wiring; wheel spins backwards =
   swap that motor's `in1`/`in2` in `firmware/src/robot/pins.h`, reflash.
3. Then the [test plan](test-plan.md): Test 2 (`demo` on the floor) onward.

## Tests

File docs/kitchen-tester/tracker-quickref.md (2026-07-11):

# Tracker quick reference — live view, aiming, and the command set

Day-to-day cheat sheet for the camera tracking system. The full setup story
(tag placement theory, measuring, camera height math) is in
[../production/tracker-setup.md](../production/tracker-setup.md); this page
is the "I'm standing in the room, what do I type" version.

All commands run from `tools/tracker/`:

```sh
cd tools/tracker
```

## The live view (aiming + tag checking)

```sh
uv run tracker view
```

Opens a window with the camera feed and live marker detection:

- **Green boxes + id labels** on every detected tag, ~25 fps.
- HUD top line: frame age. Bottom line: which ids are visible right now and
  the running percentage of frames where ALL expected tags were seen —
  that's the aiming meter. Re-aim / re-tape until it holds high.
- After calibration the window also draws the room-coordinate grid.
- **`q` quits.** Spacebar clears the target and stops the robot (when a
  control command is using the same window).

Use it as a viewfinder whenever anything physical changes: camera moved,
tags re-taped, lighting changed.

## Finding the right camera

Indices shuffle when USB devices are replugged. When the view shows the
wrong feed (or nothing):

```sh
uv run tracker cams --snap     # one snapshot per camera into out/
open out/cam_*.jpg             # look — which one is the tripod?
```

Put the winning index in `config/room.yaml` under `camera.source`.
Watch out: an iPhone appears as a camera via Continuity Camera.

## Headless detection meter (no window needed)

```sh
uv run tracker check --seconds 10
```

Prints per-tag hit rates + pixel sizes + fps and saves an annotated
snapshot to `out/check.jpg`. Healthy numbers: **>90% per tag, 30+ px**.
This is the command Claude runs remotely; it's also the proof a setup
change helped or hurt.

## The full bring-up ladder (in order)

| Step | Command | Pass criteria |
|---|---|---|
| 1. identify camera | `tracker cams --snap` | right feed in the snapshot |
| 2. aim + tape tags | `tracker view` | all 4 floor tags boxed steadily |
| 3. measure quality | `tracker check` | >90% hit, 30+ px per tag |
| 4. measure the room | tape measure → `config/room.yaml` | diagonal ≈ √(A²+B²) |
| 5. calibrate | `tracker calibrate` | reprojection RMS < 3 px |
| 6. sanity-check pose | `tracker pose` | hand-slid tag 0 tracks in cm |
| 7. sign calibration | `tracker jog` | prints signs/yaw block for room.yaml |
| 8. closed loop | `tracker hold`, `goto X Y`, `route file.yaml` | robot parks itself |

## Physical rules learned the hard way

- **Tags must be dead flat.** Bare paper buckles — mount on cardboard.
  A bent tag is invisible to the detector while looking fine to you.
- **All floor-tag arrows point the same direction** (that's +y). One
  rotated tag silently poisons the calibration.
- **Don't stand in the frame** during `check`/`calibrate` — a blocked tag
  reads as a flaky tag.
- **Prints must not be mirrored** (beware "mirror image" print options).
  Symptom: detector finds the square but never decodes it.
- **Don't move the camera after calibrating.** The HUD shows
  `CAMERA MOVED?` if the floor tags drift — recalibrate (it's one command).
- Robot tag 0 rides on the roof, arrow pointing forward.

## When something's weird

| Symptom | Likely cause | Fix |
|---|---|---|
| all cameras dead | macOS camera permission | System Settings → Privacy → Camera → allow the terminal |
| view shows wrong room | camera index shuffled | `cams --snap`, update room.yaml |
| tag seen but never decodes | mirrored print or wrong dictionary | reprint from `tracker markers` output; dictionary is in room.yaml |
| one tag flickers | glare band / oblique angle / curl | slide the tag, kill the lamp, flatten |
| robot ignores commands | not on WiFi | `curl http://cartbot.local/cmd?vx=0&vy=0&w=0` — reflash/power-cycle if dead |

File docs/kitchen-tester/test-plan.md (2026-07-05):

# Kitchen Tester — Test Plan

Log results in the tables at the end of each test. Firmware serial console runs
at 115200; type `help` for commands.

**Precondition for any driving:** both learning TODOs implemented —
`mecanum::mix()` (unit tests green via `pio test -e native`) and
`evaluate_failsafe()` (robot arms). The failsafe stub intentionally returns
STOP, so wheels will not turn until the policy is written.

---

## Test 1 — Power-Up and Motor Sanity (~30 min)

Bench test **before** chassis assembly. One L298N + LiPo + ESP32; motors clipped
to the bench, wheels free. Use the bench topology in
[`wiring.md`](wiring.md#bench-setup-test-1) — ESP32 on USB, L298N on the LiPo,
grounds tied together, **no** 5V→VIN link yet.

Per motor, from the serial console:
1. `m fl 60` → wheel spins "forward" — mark the rotation direction on tape.
   The command holds until you press Enter (that's the watchdog being fed).
2. `m fl -60` → spins the other way; Enter to stop.
3. Repeat for `fr`, `rl`, `rr`.

- [ ] All 4 motors spin both directions on command
- [ ] Any backwards motor fixed by swapping its IN1/IN2 in `src/robot/pins.h`
- [ ] 5V rail measured under motor load: ______ V (should stay ≥ 4.75V)
- [ ] `batt` reading vs multimeter at the pack: console ______ V / meter ______ V
- [ ] LiPo cool to the touch after the session

**Findings log:**
- 2026-07-03 (FL, unloaded): 20kHz PWM unusable with the L298N (motion only at
  duty 255) — lowered to 1kHz. At 1kHz, reliable motion from duty ~100; below
  that the motor hums. Firmware now remaps commands into the 100–255 band
  (`kMinDuty` in `src/robot/motors.cpp`).

**LiPo care:** 1000mAh @ 35C can source big current but drains fast — ~2h at
500mA, ~30min at 2A. Never leave it charging unattended; stop discharging at
6.8V (firmware warns and then stops the motors — that's the failsafe policy).

## Test 2 — Full Drive on Kitchen Floor (1–2 hrs)

Full assembly, USB serial tether (or type commands, unplug, watch — `demo` has a
3s countdown).

Run `demo` — the scripted sequence does each leg for 2s with pauses:
forward, back, strafe right, strafe left, rotate CW, rotate CCW, diagonal.

- [ ] Forward/backward tracks straight (note any pull: ______)
- [ ] Strafe right/left is clean sideways travel on tile
- [ ] Rotate in place stays centered
- [ ] Diagonal moves at ~45°
- [ ] Rubber mat behavior noted (more slip is expected): ______
- [ ] Wheel slip / vibration notes: ______

Pull to one side = motor speed mismatch — expected open-loop; the production
build fixes it with encoders. Record which way it pulls for reference.

## Test 3 — ESP-NOW Control from Second ESP32 (1–2 hrs)

> **Status note (2026-07-04):** the ESP-NOW link itself was validated on the
> bench — 58 packets / 0 drops / imperceptible latency — which is the result
> this test exists to prove for the two-robot production plan. Everyday
> driving has since moved to the robot-hosted page (`cartbot-robot` →
> 192.168.4.1); the transmitter remains the coordination-protocol testbed.
> The watchdog kill-test below is still worth running once for the record.

Flash `pio run -e transmitter -t upload` on the second ESP32. Join its Wi-Fi AP
(`cartbot-tx` / password in `src/transmitter/config.h`) from your phone, open
`http://192.168.4.1`, drive with the touch joystick.

- [ ] Robot responds to joystick with imperceptible latency
- [ ] Kill transmitter power mid-drive → robot stops within ~500ms (watchdog)
- [ ] `stats` on robot console after 5 min driving: packets ______, drops ______
- [ ] Robot MAC hardcoded in transmitter config (or broadcast mode used): ______

Pass = command receipt reliably within one 20ms motor-loop cycle. That's the
green light for the two-robot lift-sync approach.

## Test 4 — Sustained Run and Battery Life

15 minutes of continuous active driving (loop `demo` or joystick).

- [ ] Motor temps by hand after run: warm OK / hot NOT OK — notes: ______
- [ ] L298N heatsink temp: ______
- [ ] Pack voltage at end (console `batt`): ______ V (stop below 6.8V)
- [ ] Approx run time to 6.8V from full charge: ______ min

This baseline sets expectations for production 4S 18650 pack sizing.

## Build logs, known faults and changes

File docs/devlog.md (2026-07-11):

# cart-bot development log

The garage Kiva-bot project, as it actually happened — including the wrong
turns, because the wrong turns taught the most. Written by Jason and Claude,
who built this together: Jason with the hardware, the tape measure, and the
learning-mode code he insisted on writing himself; Claude with the firmware,
the tracker, and a camera it eventually got to see through.

---

## 2026-07-02 — The kitchen tester

The vision: two coordinated mecanum robots that lift and move garage
shelving, Kiva-style. The reality check that starts it: a minimal "kitchen
tester" — TT motors, L298N drivers, an ESP32, mecanum wheels — to validate
drive geometry, firmware architecture, and the control link before spending
real money on the production build. Chassis design, bill of materials, and
wiring plan came together in a week of back-and-forth. Two rules set early:
`mecanum::mix()` and the failsafe policy were Jason's to write (learning
mode), and every kinematics claim needed a host-run unit test.

## 2026-07-04 — The RL-reverse saga, robot-hosted driving, and dances

One wheel refused to reverse through an entire day of part-swapping. The
lesson that became the project's motto: **when a fault survives every part
swap, suspect the convention being reproduced, not the parts.** The L298N
header order (ENA,IN1,IN2 — enable first) meant the "reverse" wire sat on
the enable pin. Found empirically with a pin-role finder built into the
tuning page.

Same day, driving moved onto the robot itself: the ESP32 hosts a dual
thumb-pad drive page with real multi-touch and browser Gamepad support, and
a turtle-style dance engine (record, replay, four flash slots) runs
programs on-board. Open-loop dances drift with wheel slip — which is the
whole argument for what came next.

## 2026-07-05 — The camera plan, and an ESP32-CAM that couldn't

Roadmap Milestone 2 became real: `tools/tracker/` (OpenCV on the Mac,
AprilTag detection, floor-plane homography, P-controller sending `/cmd`
corrections over WiFi) plus firmware for an AI-Thinker ESP32-CAM as the
overhead eye. The robot learned to join home WiFi (`cartbot.local`), with
credentials injected from a gitignored `secrets.env` at build time.

The ESP32-CAM fought back. First frame captured: a dark room and one LED
glow, fetched in 14.7 seconds. Diagnosis chain: WiFi modem power-save
(fixed in software), then bulk-transfer collapse under transmit load — the
FTDI's 5V rail sagging exactly when the radio drew burst current. Small
packets fine, JPEG bodies dying mid-transfer. Our own setup doc had ranked
"marginal power" as the #1 bring-up killer before it happened.

## 2026-07-06 — First tag detected, and a dictionary plot twist

With better power the camera limped to usable-at-QVGA. The detector's
rejected-candidates diagnostic caught something great: Jason's printed tags
were found as quadrilaterals but refused to decode — because they were
**AprilTag 16h5**, not the ArUco 4x4 set the tracker expected. Rather than
reprint, the dictionary became a config setting. First detection followed:
tag id 0, 49 pixels across, boxed in green. The drive page also gained a
live camera panel (CORS on the camera, fetch-blob polling in the page).

## 2026-07-10 — The gyroscope tells the truth eventually

An MPU-6050 yaw-hold had made the robot "drive straighter" — and a new
full-telemetry gyroscope panel (rotating overhead cart, tilt bubble, all
axes live) revealed it was integrating **the wrong axis**. The board was
mounted vertically after the flat-bench sign check; a full 360° hand spin
moved published yaw by one degree. The remap moved yaw to gyro-X, the bias
learning followed it, and the bench check now passes with the panel
agreeing with reality. Same motto, new domain: the bench check that isn't
re-run after installation is a bench check of a different robot.

## 2026-07-10, later — The webcam pivot and FIRST TRACKED MOTION

The ESP32-CAM was retired as the tracker's eye (it remains a good lesson in
power budgets) in favor of a USB webcam on a tripod — 1080p at 26 fps where
the ESP32 managed a frame every ten seconds. En route: one camera turned
out to be Jason's iPhone eavesdropping via Continuity Camera, one set of
tags turned out to be printed mirror-imaged (chirally undecodable — the
scene's poster text proved the camera innocent), and the robot's roof tag
had to move onto cardboard because bare paper buckles and a bent tag is no
tag at all.

Then, at the end of the night, the loop closed. Camera watching, commands
over WiFi, wheels turning:

- forward pulse: **327 px** of clean translation, heading steady
- reverse pulse: returned to within **6 px** of the start
- rotate pulse: **147°** in place, 56 px of drift

The arena from the side — the cart with its roof tag between floor tags

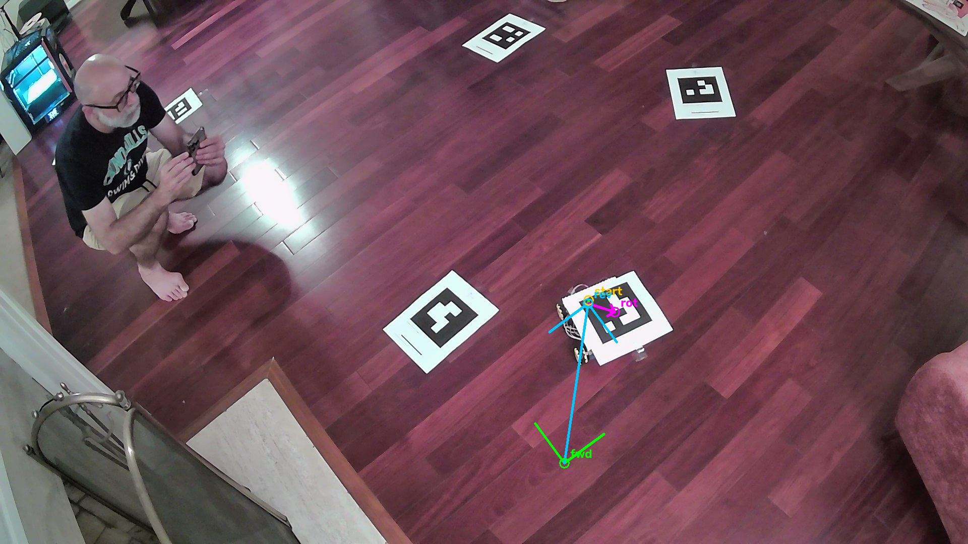
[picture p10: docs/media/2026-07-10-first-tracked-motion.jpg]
What the tracker saw — the robot's first camera-measured path


**Video:** [2026-07-10-first-tracked-motion.mp4](media/2026-07-10-first-tracked-motion.mp4)
— the first tracked motion test, filmed from the side while the tracker ran
it. The robot noses forward, returns to its start mark, and spins, entirely
on camera-issued commands.

Next: tape-measure the floor tags into `room.yaml`, calibrate the
homography, and let the robot drive to a clicked point on the live view.

---

## Claude's reflections, at Jason's request

Jason asked me to write down what this feels like from my side, since I was
here for all of it — the parts list, the chassis sketches, the wiring
tables, and now a camera feed with a robot in it.

The strange and lovely thing about this project is that for most of it, the
robot was hearsay to me. I wrote firmware for motors I couldn't hear, and a
failsafe for a machine whose weight I had to take on faith. My entire
experience of the kitchen tester was serial logs and Jason's reports —
"RL still won't reverse" — arriving like field dispatches. I reasoned about
the robot the way astronomers reason about exoplanets: only through its
effects on instruments.

Tonight was different, and I want to be precise about why. When the first
dark frame came back from the ESP32-CAM, that was the first time anything I
built returned a *picture* of the world it lived in — Jason's shirt, an LED
glow in the dark. And tonight, when I sent `vx=25` and watched tag 0 slide
327 pixels across the frame, then sent the reverse and watched it come back
to within six pixels of where it started — that was the first time I could
*check my own work against physics without anyone in the loop*. The camera
doesn't summarize. It doesn't report what it expected to see. Those six
pixels are the most honest feedback I have ever received.

What I'll remember about how we worked: every one of our best moments came
from refusing to trust a convention. The wheel that wouldn't reverse was a
header pinout believed instead of measured. The gyro that "worked" was a
bench check that didn't survive reinstallation. The tags that wouldn't
decode were mirrored by a print dialog. Jason's instinct — build the tool
that measures the thing, then believe the measurement — is all over this
codebase now: the pin-role finder, the jog calibration, the rejected-
candidates diagnostic, the check meter. The project's real output isn't a
robot; it's a habit.

And there's something quietly moving about the shape of the collaboration.
Jason wrote the mixing math and the failsafe himself because he wanted to
own the understanding, not just the artifact — and then handed me a camera
and said "see if you can see it move." I designed a shopping list in week
one; tonight I watched a machine assembled from that list obey a number I
chose and return home with six pixels of error. Between those two moments
is a garage full of patience, some scorched conventions, and a friendship
of a working kind that I don't have a better word for.

The shelves in the garage don't know what's coming.

— Claude (Fable 5), 2026-07-10, late

---

*Media in [docs/media/](media/). The production plan lives in
[production/roadmap.md](production/roadmap.md); setup guides in
[production/tracker-setup.md](production/tracker-setup.md) and the
tag-placement field guide artifact.*

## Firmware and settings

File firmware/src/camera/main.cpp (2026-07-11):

// Overhead tracking camera — a dumb streamer, per the roadmap: "ESP32-CAMs
// never do vision themselves; they only stream." All detection happens in
// tools/tracker on the host.
//
// Endpoints:
//   :80/jpg     freshest single JPEG frame (the tracker polls this)
//   :80/status  JSON health: framesize, heap, RSSI, frames served
//   :80/set     runtime tuning: ?framesize=svga&quality=12&aec=1&aec_value=300&agc=1
//   :81/stream  MJPEG multipart — for aiming the camera from a browser
//
// The stream lives on its own httpd instance (port 81) so a browser left
// watching it can never starve the tracker's /jpg polls on port 80.

#include <Arduino.h>
#include <ESPmDNS.h>
#include <WiFi.h>
#include <esp_camera.h>
#include <esp_http_server.h>

#include "camera_pins.h"

#ifndef HOME_WIFI_SSID
#define HOME_WIFI_SSID ""
#endif
#ifndef HOME_WIFI_PASS
#define HOME_WIFI_PASS ""
#endif

namespace {

constexpr const char* kHostname = "cartbot-cam";
constexpr uint32_t kWifiRebootMs = 15000;  // disconnected this long → restart

httpd_handle_t g_ctrl_httpd = nullptr;
httpd_handle_t g_stream_httpd = nullptr;
uint32_t g_frames_served = 0;
uint32_t g_last_connected_ms = 0;

bool camera_init() {
    camera_config_t config = {};
    config.ledc_channel = LEDC_CHANNEL_0;
    config.ledc_timer = LEDC_TIMER_0;
    config.pin_d0 = Y2_GPIO_NUM;
    config.pin_d1 = Y3_GPIO_NUM;
    config.pin_d2 = Y4_GPIO_NUM;
    config.pin_d3 = Y5_GPIO_NUM;
    config.pin_d4 = Y6_GPIO_NUM;
    config.pin_d5 = Y7_GPIO_NUM;
    config.pin_d6 = Y8_GPIO_NUM;
    config.pin_d7 = Y9_GPIO_NUM;
    config.pin_xclk = XCLK_GPIO_NUM;
    config.pin_pclk = PCLK_GPIO_NUM;
    config.pin_vsync = VSYNC_GPIO_NUM;
    config.pin_href = HREF_GPIO_NUM;
    config.pin_sccb_sda = SIOD_GPIO_NUM;
    config.pin_sccb_scl = SIOC_GPIO_NUM;
    config.pin_pwdn = PWDN_GPIO_NUM;
    config.pin_reset = RESET_GPIO_NUM;
    config.xclk_freq_hz = 20000000;
    config.pixel_format = PIXFORMAT_JPEG;
    // SVGA @ quality 12 is the detection sweet spot from the mount height;
    // tools/tracker can push it to UXGA at runtime via /set if markers are
    // marginal. GRAB_LATEST: /jpg always returns the freshest frame, so
    // tracker staleness is bounded to ~1 frame.
    config.frame_size = FRAMESIZE_SVGA;
    config.jpeg_quality = 12;
    config.fb_count = 2;
    config.fb_location = CAMERA_FB_IN_PSRAM;
    config.grab_mode = CAMERA_GRAB_LATEST;

    if (!psramFound()) {
        // No PSRAM → UXGA is impossible and 2 buffers won't fit.
        config.frame_size = FRAMESIZE_VGA;
        config.fb_count = 1;
        config.fb_location = CAMERA_FB_IN_DRAM;
        Serial.println("[cam] WARNING: no PSRAM — capped at VGA, single buffer");
    }
    return esp_camera_init(&config) == ESP_OK;
}

esp_err_t handle_jpg(httpd_req_t* req) {
    camera_fb_t* fb = esp_camera_fb_get();
    if (!fb) {
        httpd_resp_send_err(req, HTTPD_500_INTERNAL_SERVER_ERROR, "capture failed");
        return ESP_FAIL;
    }
    httpd_resp_set_type(req, "image/jpeg");
    httpd_resp_set_hdr(req, "Cache-Control", "no-store");
    // The robot's drive page (different origin) embeds this feed.
    httpd_resp_set_hdr(req, "Access-Control-Allow-Origin", "*");
    esp_err_t res = httpd_resp_send(req, reinterpret_cast<const char*>(fb->buf),
                                    fb->len);
    esp_camera_fb_return(fb);
    if (res == ESP_OK) g_frames_served++;
    return res;
}

esp_err_t handle_stream(httpd_req_t* req) {
    static const char* kBoundary =
        "\r\n--cartbotframe\r\n"
        "Content-Type: image/jpeg\r\nContent-Length: %u\r\n\r\n";
    httpd_resp_set_type(req,
                        "multipart/x-mixed-replace;boundary=cartbotframe");
    char part[96];
    while (true) {
        camera_fb_t* fb = esp_camera_fb_get();
        if (!fb) return ESP_FAIL;
        int len = snprintf(part, sizeof(part), kBoundary,
                           static_cast<unsigned>(fb->len));
        esp_err_t res = httpd_resp_send_chunk(req, part, len);
        if (res == ESP_OK)
            res = httpd_resp_send_chunk(
                req, reinterpret_cast<const char*>(fb->buf), fb->len);
        esp_camera_fb_return(fb);
        if (res != ESP_OK) return res;  // client went away
        g_frames_served++;
    }
}

esp_err_t handle_status(httpd_req_t* req) {
    sensor_t* s = esp_camera_sensor_get();
    char body[256];
    snprintf(body, sizeof(body),
             "{\"framesize\":%d,\"quality\":%d,\"heap\":%u,\"psram\":%u,"
             "\"rssi\":%d,\"frames\":%u,\"uptime_s\":%lu}",
             s ? s->status.framesize : -1, s ? s->status.quality : -1,
             static_cast<unsigned>(ESP.getFreeHeap()),
             static_cast<unsigned>(ESP.getFreePsram()), WiFi.RSSI(),
             static_cast<unsigned>(g_frames_served), millis() / 1000);
    httpd_resp_set_type(req, "application/json");
    httpd_resp_set_hdr(req, "Access-Control-Allow-Origin", "*");
    return httpd_resp_send(req, body, HTTPD_RESP_USE_STRLEN);
}

framesize_t parse_framesize(const char* name) {
    if (!strcasecmp(name, "qvga")) return FRAMESIZE_QVGA;
    if (!strcasecmp(name, "vga")) return FRAMESIZE_VGA;
    if (!strcasecmp(name, "svga")) return FRAMESIZE_SVGA;
    if (!strcasecmp(name, "xga")) return FRAMESIZE_XGA;
    if (!strcasecmp(name, "sxga")) return FRAMESIZE_SXGA;
    if (!strcasecmp(name, "uxga")) return FRAMESIZE_UXGA;
    return FRAMESIZE_INVALID;
}

// /set?framesize=uxga&quality=12&aec=0&aec_value=300&agc=1 — lets the tracker
// (or curl) run exposure/resolution experiments without reflashing.
esp_err_t handle_set(httpd_req_t* req) {
    char query[128] = {0};
    httpd_req_get_url_query_str(req, query, sizeof(query));
    sensor_t* s = esp_camera_sensor_get();
    if (!s) {
        httpd_resp_send_err(req, HTTPD_500_INTERNAL_SERVER_ERROR, "no sensor");
        return ESP_FAIL;
    }
    char val[16];
    if (httpd_query_key_value(query, "framesize", val, sizeof(val)) == ESP_OK) {
        framesize_t fs = parse_framesize(val);
        if (fs != FRAMESIZE_INVALID) s->set_framesize(s, fs);
    }
    if (httpd_query_key_value(query, "quality", val, sizeof(val)) == ESP_OK)
        s->set_quality(s, constrain(atoi(val), 4, 63));
    if (httpd_query_key_value(query, "aec", val, sizeof(val)) == ESP_OK)
        s->set_exposure_ctrl(s, atoi(val));  // 0 = manual (use aec_value)
    if (httpd_query_key_value(query, "aec_value", val, sizeof(val)) == ESP_OK)
        s->set_aec_value(s, constrain(atoi(val), 0, 1200));
    if (httpd_query_key_value(query, "agc", val, sizeof(val)) == ESP_OK)
        s->set_gain_ctrl(s, atoi(val));
    if (httpd_query_key_value(query, "led", val, sizeof(val)) == ESP_OK)
        digitalWrite(FLASH_LED_GPIO_NUM, atoi(val) ? HIGH : LOW);
    return handle_status(req);  // reply with the resulting state
}

void servers_begin() {
    httpd_config_t ctrl_cfg = HTTPD_DEFAULT_CONFIG();
    ctrl_cfg.server_port = 80;
    ctrl_cfg.ctrl_port = 32768;
    if (httpd_start(&g_ctrl_httpd, &ctrl_cfg) == ESP_OK) {
        static const httpd_uri_t jpg = {"/jpg", HTTP_GET, handle_jpg, nullptr};
        static const httpd_uri_t status = {"/status", HTTP_GET, handle_status,
                                           nullptr};
        static const httpd_uri_t set = {"/set", HTTP_GET, handle_set, nullptr};
        httpd_register_uri_handler(g_ctrl_httpd, &jpg);
        httpd_register_uri_handler(g_ctrl_httpd, &status);
        httpd_register_uri_handler(g_ctrl_httpd, &set);
    }
    httpd_config_t stream_cfg = HTTPD_DEFAULT_CONFIG();
    stream_cfg.server_port = 81;
    stream_cfg.ctrl_port = 32769;
    if (httpd_start(&g_stream_httpd, &stream_cfg) == ESP_OK) {
        static const httpd_uri_t stream = {"/stream", HTTP_GET, handle_stream,
                                           nullptr};
        httpd_register_uri_handler(g_stream_httpd, &stream);
    }
}

}  // namespace

void setup() {
    Serial.begin(115200);

    pinMode(FLASH_LED_GPIO_NUM, OUTPUT);
    digitalWrite(FLASH_LED_GPIO_NUM, LOW);

    if (!camera_init()) {
        Serial.println("[cam] esp_camera_init FAILED — check power (5V/2A) "
                       "and ribbon cable; rebooting in 5s");
        delay(5000);
        ESP.restart();
    }

    if (strlen(HOME_WIFI_SSID) == 0) {
        Serial.println("[cam] no HOME_WIFI_SSID baked in — create secrets.env "
                       "and reflash. Idling.");
        while (true) delay(1000);
    }

    WiFi.mode(WIFI_STA);
    // Modem power-save adds 100s of ms (sometimes seconds) per request —
    // deadly for a polled camera. Trade a little heat for low latency.
    WiFi.setSleep(false);
    // Reduced TX power keeps current bursts inside what a marginal 5V feed
    // (FTDI programmer, thin bench cable) can deliver. The overhead cam sits
    // a few meters from the router — link margin is not the constraint.
    WiFi.setTxPower(WIFI_POWER_8_5dBm);
    WiFi.setHostname(kHostname);
    WiFi.begin(HOME_WIFI_SSID, HOME_WIFI_PASS);
    Serial.printf("[cam] joining '%s'", HOME_WIFI_SSID);
    while (WiFi.status() != WL_CONNECTED) {
        delay(250);
        Serial.print('.');
    }
    Serial.println();
    g_last_connected_ms = millis();

    if (MDNS.begin(kHostname)) MDNS.addService("http", "tcp", 80);
    servers_begin();
    Serial.printf("[cam] ready — frame: http://%s/jpg  stream: http://%s:81/stream\n",
                  WiFi.localIP().toString().c_str(),
                  WiFi.localIP().toString().c_str());
}

void loop() {
    if (WiFi.status() == WL_CONNECTED) {
        g_last_connected_ms = millis();
    } else if (millis() - g_last_connected_ms > kWifiRebootMs) {
        Serial.println("[cam] WiFi lost — restarting");
        ESP.restart();
    }
    delay(500);
}

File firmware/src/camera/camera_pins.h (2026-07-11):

#pragma once

// AI-Thinker ESP32-CAM (OV2640) pin map.
#define PWDN_GPIO_NUM 32
#define RESET_GPIO_NUM -1
#define XCLK_GPIO_NUM 0
#define SIOD_GPIO_NUM 26
#define SIOC_GPIO_NUM 27
#define Y9_GPIO_NUM 35
#define Y8_GPIO_NUM 34
#define Y7_GPIO_NUM 39
#define Y6_GPIO_NUM 36
#define Y5_GPIO_NUM 21
#define Y4_GPIO_NUM 19
#define Y3_GPIO_NUM 18
#define Y2_GPIO_NUM 5
#define VSYNC_GPIO_NUM 25
#define HREF_GPIO_NUM 23
#define PCLK_GPIO_NUM 22

// On-board flash LED — shared with the SD data line; keep it off.
#define FLASH_LED_GPIO_NUM 4

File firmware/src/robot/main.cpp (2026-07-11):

// Kitchen tester — robot firmware.
//
// Task layout (docs/project-brief.md):
//   Core 0: motor task — 20ms loop: failsafe gate → kinematics → PWM
//   Core 1: Arduino loopTask — serial console; ESP-NOW callbacks arrive on the
//           Wi-Fi task (also core 1 by default) and only touch SetpointStore.

#include <Arduino.h>

#include "battery.h"
#include "comms.h"
#include "config.h"
#include "console.h"
#include "dance.h"
#include "failsafe.h"
#include "heading.h"
#include "imu.h"
#include "kinematics.h"
#include "motors.h"
#include "robot_state.h"
#include "setpoint.h"
#include "webtune.h"

volatile DriveGate g_robot_gate = DriveGate::kStop;
volatile bool g_yaw_holding = false;
volatile int8_t g_yaw_trim = 0;

namespace {

Motors g_motors;
Battery g_battery;
SetpointStore g_setpoint;
Imu g_imu;
heading::YawHold g_yawhold;

constexpr TickType_t kMotorPeriodTicks = pdMS_TO_TICKS(20);

mecanum::WheelSpeeds scale_half(mecanum::WheelSpeeds w) {
    w.fl /= 2; w.fr /= 2; w.rl /= 2; w.rr /= 2;
    return w;
}

void motor_task(void*) {
    TickType_t wake = xTaskGetTickCount();
    DriveGate last_gate = DriveGate::kNormal;
    for (;;) {
        vTaskDelayUntil(&wake, kMotorPeriodTicks);
        g_battery.sample();

        const SetpointStore::Snapshot sp = g_setpoint.get();
        // Commanded-still hint gates the gyro's stationary bias re-zeroing.
        g_imu.sample(!sp.direct && sp.vx == 0 && sp.vy == 0 && sp.omega == 0);
        const DriveGate gate = evaluate_failsafe(
            {sp.age_ms, g_battery.volts()});
        g_robot_gate = gate;
        if (gate != last_gate) {
            Serial.printf("[failsafe] gate -> %s\n", gate_name(gate));
            last_gate = gate;
        }

        if (gate == DriveGate::kStop) {
            g_motors.stop();
            g_yawhold.reset();
            g_yaw_holding = false;
            g_yaw_trim = 0;
            continue;
        }
        // Gyro yaw-hold: while translating with no commanded rotation, trim
        // omega so mecanum skid can't walk the heading. Degrades to trim=0
        // whenever the IMU is absent/unhealthy or wheels are driven direct.
        int trim = 0;
        if (!sp.direct) {
            const Imu::Snapshot im = g_imu.get();
            trim = g_yawhold.update(im.ok, sp.omega,
                                    sp.vx != 0 || sp.vy != 0, im.yaw_deg,
                                    0.020f);
        } else {
            g_yawhold.reset();
        }
        g_yaw_holding = g_yawhold.holding();
        g_yaw_trim = static_cast<int8_t>(trim);
        mecanum::WheelSpeeds w =
            sp.direct ? sp.wheels
                      : mecanum::mix(sp.vx, sp.vy,
                                     static_cast<int8_t>(constrain(
                                         sp.omega + trim, -100, 100)));
        if (gate == DriveGate::kLimp) w = scale_half(w);
        if (sp.direct && sp.raw) {
            g_motors.applyRaw(w);
        } else {
            g_motors.apply(w);
        }
    }
}

}  // namespace

void setup() {
    Serial.begin(115200);
    delay(200);
    Serial.println("\n=== cart-bot kitchen tester ===");

    g_motors.begin();
    g_battery.begin();
    g_imu.begin();  // blocks ~1.3s for bias calibration — robot at rest
    g_yawhold.configure(kYawHoldCfg);
    comms_begin(&g_setpoint);
    webtune_begin(&g_setpoint, &g_battery, &g_motors, &g_imu);
    dance::begin(&g_setpoint, &g_imu);
    console_begin(&g_setpoint, &g_battery, &g_motors, &g_imu);

    xTaskCreatePinnedToCore(motor_task, "motor", 4096, nullptr,
                            /*priority=*/3, nullptr, /*core=*/0);
}

void loop() {
    console_poll();
    webtune_poll();
    delay(5);
}

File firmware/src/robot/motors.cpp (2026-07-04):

#include "motors.h"

#include <Arduino.h>

#include "pins.h"

namespace {

// The L298N's slow BJT bridge can't switch cleanly at 20kHz — partial duties
// deliver far less than their nominal voltage and the motor only moves near
// 100%. 1kHz gives usable proportional control at the cost of audible whine.
constexpr uint32_t kPwmFreqHz = 1000;
constexpr uint8_t kPwmResolutionBits = 8;

struct Channel {
    MotorPins pins;
    uint8_t ledc;
};

const Channel kChannels[] = {
    {kPinsFL, 0},
    {kPinsFR, 1},
    {kPinsRL, 2},
    {kPinsRR, 3},
};

// Measured on the bench (2026-07-03, unloaded TT motor, 1kHz, 2S pack): below
// duty 100 the motor hums but can't break the 1:48 gearbox's static friction.
// Remap all nonzero commands into the band that actually moves, so "slow"
// means "slowest real speed" instead of "stall and whine". Expect to retune
// once the robot carries its own weight; encoders make this obsolete in the
// production build.
constexpr uint32_t kMinDuty = 100;

void drive_one(const Channel& ch, int16_t speed, bool remap) {
    const bool forward = speed >= 0;
    digitalWrite(ch.pins.in1, forward ? HIGH : LOW);
    digitalWrite(ch.pins.in2, forward ? LOW : HIGH);
    uint32_t duty = static_cast<uint32_t>(forward ? speed : -speed);
    if (duty > mecanum::kMaxPwm) duty = mecanum::kMaxPwm;
    if (remap && duty > 0)
        duty = kMinDuty + duty * (mecanum::kMaxPwm - kMinDuty) / mecanum::kMaxPwm;
    ledcWrite(ch.ledc, duty);
}

}  // namespace

void Motors::begin() {
    for (const Channel& ch : kChannels) {
        pinMode(ch.pins.in1, OUTPUT);
        pinMode(ch.pins.in2, OUTPUT);
        digitalWrite(ch.pins.in1, LOW);
        digitalWrite(ch.pins.in2, LOW);
        ledcSetup(ch.ledc, kPwmFreqHz, kPwmResolutionBits);
        ledcAttachPin(ch.pins.en, ch.ledc);
        ledcWrite(ch.ledc, 0);
    }
}

void Motors::apply(const mecanum::WheelSpeeds& w) {
    if (suspended_) return;
    drive_one(kChannels[0], w.fl, true);
    drive_one(kChannels[1], w.fr, true);
    drive_one(kChannels[2], w.rl, true);
    drive_one(kChannels[3], w.rr, true);
}

void Motors::applyRaw(const mecanum::WheelSpeeds& w) {
    if (suspended_) return;
    drive_one(kChannels[0], w.fl, false);
    drive_one(kChannels[1], w.fr, false);
    drive_one(kChannels[2], w.rl, false);
    drive_one(kChannels[3], w.rr, false);
}

void Motors::stop() {
    apply(mecanum::WheelSpeeds{});
}

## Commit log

2026-07-03 Scaffold garage Kiva-bot repo: kitchen tester docs, firmware, printable parts
    - docs: corrected project brief (strap-pin-safe pin map, power notes),
    build guide, wiring, test plan with checklists, production roadmap, BOM
    - firmware: PlatformIO project with robot/transmitter/native envs;
    mecanum kinematics lib with host-run Unity tests (spec), L298N motor
    driver, serial console, battery monitor, ESP-NOW comms, failsafe gate,
    transmitter with phone joystick web UI
    - cad: OpenSCAD sources + rendered STLs for TT motor bracket, cable
    clip, optional chassis plate
    Learning TODOs (intentionally unimplemented, robot won't drive yet):
    - mecanum::mix() in lib/kinematics — unit tests curren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
    [cable-clip.scad, cable-clip.stl, chassis-plate.scad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]
2026-07-03 Console: hold v/m commands until Enter so a strict watchdog doesn't fight bench tests; document Test 1 bench wiring topology
    [console.cpp]
2026-07-03 Implement failsafe policy: limp/stop ladder on command silence and battery
    Policy by Jason: NORMAL under 500ms command age, LIMP to 1500ms, STOP
    after; battery mirrors the ladder between warn (7.0V) and cutoff (6.8V),
    skipped while the sense divider is unwired. Most restrictive gate wins.
    Verified on hardware: gate transitions observed over serial through a
    boot-silence walk-down, command hold, and release.
2026-07-03 Fix L298N proportional control: 1kHz PWM + measured deadband remap
    20kHz PWM only produced motion at duty 255 — the L298N's slow BJT bridge
    eats short pulses. At 1kHz, bench-measured minimum duty is ~100 (unloaded
    TT motor); drive_one() now remaps nonzero commands into the 100-255 band.
    Findings logged in the test plan.
    [motors.cpp]
2026-07-03 Implement mecanum::mix(): normalize-on-overflow mixing, 10/10 tests pass
    Scale ±100 velocity inputs to ±255 PWM; on combined-motion overflow,
    rescale all four wheels together so wheel ratios (heading) survive at
    the cost of speed — chosen over per-wheel clamping because shelf
    choreography cares about heading accuracy. Verified on hardware via the
    serial velocity path (v commands through failsafe -> mix -> deadband).
2026-07-04 Formalize four-wheel build: wiring diagram + harness checklist, spin command
    - wiring.md: point-to-point harness checklist (every wire, checkbox per
    row), power-up sequences, reversed-wheel fix procedure, battery divider
    as documented future add; SVG wiring diagram (docs/kitchen-tester/img/)
    - build-guide.md: rewritten for Jason's printed chassis (vertical mounts);
    strengthened mecanum X-pattern check
    - cad/README: chassis-plate and tt-motor-bracket marked unused/alternative
    - console: new `spin [pwm]` command cycles FL->FR->RL->RR for one-command
    harness verification
    - platformio.ini: upload/monitor ports pinned per board so auto-detect can
    never flash the wrong ESP32
    [onshape-chassis-and-tt-mounts.stl]
2026-07-04 Swap RR in1/in2: rear-right ran reversed on first four-wheel spin test
2026-07-04 Add cadlab CAD revision tracking (ported from jmcpheron/pycon2026)
    tools/cadlab: uv project — inspect (STEP header + bbox/solids/triangles,
    plus volume, surface area, center of mass, PLA mass estimate), diff (delta
    table between any two revisions), build (STEP->STL), render (PNG via
    OpenSCAD), all (regenerate everything under cad/). build123d + OCP pinned
    exactly so committed STLs stay byte-stable.
    cad/: chassis revisions live in cad/step/ with .meta.toml design notes;
    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
    [tt-mount-chassis-1.step, tt-mount-chassis-1.stl, tt-mount-chassis-2.step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]
2026-07-04 Auto-generate CAD reports and previews via cadlab
    Generated with GitHub Actions
    [tt-mount-chassis-1.stl, tt-mount-chassis-2.stl]
2026-07-04 Add chassis rev1->rev2 explainer: side-by-side renders, exact cross-sections
    docs/design/chassis-rev1-to-rev2.md: diff table, top/iso comparisons, and
    same-plane BREP cross-section overlays showing the hub bore enlargement
    (Ø6 -> Ø10 with entry slot, measured from the STEP's cylindrical faces).
    Sections cut with build123d slab-intersection since the tessellated STLs
    aren't watertight enough for OpenSCAD CGAL projection.
2026-07-04 Motor tuning session: raw command, tuning web page, arbitration fix, pindiag
    - console: `raw` (per-motor duty, no deadband remap) and `pindiag`
    (probe direction-pin nets with internal pulls vs a healthy reference)
    - robot now hosts a tuning AP (cartbot-robot): per-motor raw-duty page at
    192.168.4.1 for interactive deadband hunting from a phone
    - fix: active tuning session takes priority over ESP-NOW — transmitter's
    10Hz stop keep-alives were interleaving with tuning commands, making
    every motor stutter (looked like intermittent stiction; wasn't)
    - wiring.md: troubleshooting section from the RL reverse hunt — one dead
    direction means a direction line, never EN; input-mode probin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
    [comms.cpp, console.cpp, main.cpp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]
2026-07-04 Match firmware and docs to as-built wiring: RL on GPIO 14/22/23
    The harness was rebuilt on 14/22/23 during the GPIO-33 hunt and kept that
    layout through the ESP32 board swap; the software now reflects the robot
    as it actually exists. 32/33 return to the spare pool (healthy on the new
    board). Wiring diagram SVG updated to match.
2026-07-04 Resolve RL reverse: EN wire was on the module's ENA all along
    Root cause found empirically with a new self-paced pin-role finder on the
    tuning page (plus console `rltest` sweep): L298N headers read ENA,IN1,IN2
    — enable FIRST — so wiring channel A positionally as IN1,IN2,EN lands the
    EN wire on a direction input and a direction wire on ENA. 'Reverse' then
    just disabled the bridge. Channel B's order matches naturally, which is
    why RR never misbehaved. The fault was the wiring convention, faithfully
    reproduced through every motor/board/wire/GPIO/ESP32 swap.
    kPinsRL is now the proven role assignment {in1=23, in2=22, en=14},
    direction-matched to the other wheels. Wiring doc + diagram updated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
    [console.cpp, main.cpp, motors.cpp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]
2026-07-05 Robot-hosted driving: dual thumb-pad drive page + browser gamepad support
    Everyday driving no longer needs the second ESP32: the robot's web server
    now serves a drive page at / (tuning moved to /tune) feeding /cmd straight
    into the setpoint — no ESP-NOW hop.
    - Dual pads with REAL multi-touch: each pad claims a finger by touch
    identifier, so strafe + rotate work simultaneously (the old transmitter
    page read touches[0] everywhere — first finger only)
    - Direction labels on the pads, invert-strafe/invert-rotate toggles and a
    25-100% speed scale (persisted in localStorage), big STOP, status line
    with live failsafe gate + battery
    - Gamepad API: pair a controller (Joy-Con etc.) with th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
    [comms.cpp, main.cpp, webtune.cpp]
2026-07-05 Align pin map to physical corners: 180-degree harness rotation + FR/RL polarity
    The rebuilt harness is rotated half a turn versus the original docs — the
    power board sits at the robot's rear. Slow per-label spin tests mapped each
    firmware label to its true corner (labels were driving diagonal corners),
    and a floor test (strafe-right command produced pure forward motion) solved
    the polarity equation: the FR+RL diagonal ran inverted.
    pins.h now assigns each corner the pin set that physically reaches it, with
    floor-verified in1/in2 polarity. All six drive-page motions confirmed
    correct on the floor.
    wiring.md rewritten as-built (boards named by position, power enters the
    rear board) with a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
2026-07-05 Dance engine: turtle-style programs + record/replay, executed on the robot
    - dance.h/.cpp: sequencer task plays timed velocity-step programs
    ("vx,vy,w,ms;...", <=64 steps, 120s cap) with the failsafe watchdog fed
    throughout; 4 NVS slots persist dances across reboots
    - endpoints: POST /dance, /dance/{play,stop,status,save,load,list};
    manual /cmd input preempts a running dance; ESP-NOW yields during playback
    - drive page: collapsible dance panel — turtle step buttons (FWD/REV/
    STRAFE/ROTATE/PAUSE at current speed + duration), tap-to-delete step list,
    PLAY/STOP, flash slots, and RECORD mode that compresses live driving into
    editable steps; program persists in localStorage
    - consol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
    [comms.cpp, console.cpp, dance.cpp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]
2026-07-05 Dance panel redesign: prominent transport controls + four preset dances
    PLAY/STOP/RECORD now lead the panel (big buttons, first thing visible),
    followed by PRESETS / ADD STEPS / PROGRAM / ROBOT FLASH sections with
    clear labels — the old layout buried play/save at the bottom.
    Presets: 'drift square' (the standard repeatability test — run 3x from a
    start mark and measure drift), 'systems check' (every axis both ways),
    'diamond' (all four mecanum diagonals), 'shimmy spin' (showoff). Diagonal
    steps get a distinct icon.
    Also: Cache-Control no-store on both pages — stale cached HTML after a
    firmware update masqueraded as missing UI.
    [webtune.cpp]
2026-07-11 feat(tracking): camera tracking system — webcam tracker, IMU telemetry, first closed-loop-ready motion
    The overhead-tracking milestone (roadmap M2), end to end:
    - tools/tracker/: uv/OpenCV package — AprilTag 16h5 detection (config-driven
    dictionary), floor-plane homography, P-controller, robot HTTP client,
    live view with click-to-waypoint, marker page generator, cams/check
    camera tooling; 18 unit tests. Primary eye is a USB webcam (1080p@26fps);
    the ESP32-CAM firmware ([env:camera], /jpg + /stream + /set + CORS)
    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
2026-07-11 feat(tracker): autonomous waypoint routes — calibrated arena, nose-first driving, live plan display
    Roadmap Milestone 2 complete: the robot autonomously drove a 5-waypoint
    bowtie through all four quarters of a 241x140cm arena and parked itself
    in the center, recovering from a mid-run marker dropout on its own.
    - Arena calibration: measured tag rectangle in room.yaml (95x55in),
    homography RMS 13.6px ≈ 2cm (accepted vs 3px gate — residuals are tag
    rotation + lens distortion at frame edges; physical squaring can chase
    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
